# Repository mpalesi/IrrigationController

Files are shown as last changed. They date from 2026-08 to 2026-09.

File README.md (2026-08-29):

# IrrigationController Firmware

Milestone 1 is an ESP-IDF 5.5.5 foundation for the Freenove FNK0090 `DEV_KIT`.
The application core uses only logical output IDs; board selection happens in the
HAL board-composition layer.

For the DEV_KIT web test, local zones 1-8 use GPIO 16, 17, 18, 19, 21, 22, 23,
and 25 respectively. The development-only Master Valve driver uses GPIO 26.

## Host tests

```sh
cmake -S tests -B build/host-tests
cmake --build build/host-tests
ctest --test-dir build/host-tests --output-on-failure
```

## DEV_KIT build, flash, and monitor

After activating ESP-IDF 5.5.5:

```sh
idf.py -C firmware set-target esp32
idf.py -C firmware build
idf.py -C firmware -p <serial-port> flash monitor
```

`IRRIGATION_CONTROLLER` is intentionally an unconfigured safe placeholder.
It contains no GPIO, MCP23017, relay-channel, or relay-polarity assumptions.

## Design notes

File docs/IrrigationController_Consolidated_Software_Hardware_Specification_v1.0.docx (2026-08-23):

IrrigationController
Consolidated Software & Hardware Specification

Version 1.0 — Implementation Baseline

Item | Value
Purpose | Wi-Fi irrigation controller with local web interface and programmable irrigation
MCU | ESP32-WROOM-32E, LCSC C701342
PCB status | Hardware design frozen; PCB/PCBA prepared for JLCPCB
Role | Single implementation reference for firmware development and Codex

# 1. Scope and status

This document consolidates the previously separate software specifications into one implementation-oriented reference. The original documents remain archival/source material; firmware implementation should use this document as the primary baseline. The architecture remains modular, deterministic, testable, event-driven and hardware-independent above the HAL.

The PCB design has been frozen and prepared for JLCPCB assembly. Hardware-specific assumptions that still require physical-board verification are explicitly identified rather than guessed.

# 2. Final hardware platform

Block | Final hardware | Software consequence
MCU | ESP32-WROOM-32E (U301), LCSC C701342 | Main controller and Wi-Fi MCU
USB | CP2102N-Axx-xQFN24 (U302) | USB/serial development and service
I/O expander | MCP23017T-E/SS (U401) | Additional digital I/O
Output driver | ULN2803A (U501) and relay drive circuitry | Hidden behind Output Driver/HAL
Actuators | 8 × Omron G5LE-family 5 V relays K601–K608 | Eight logical output channels
Field output | J702, 8 positions; relay contacts switch 24 VAC valve circuit | Logical zones map to physical outputs
Master Valve | Remote valve controlled by Shelly 1 Gen 3 over Wi-Fi/LAN | Controlled by Master Valve Service through a dedicated Shelly client/driver; independent of local PCB relay outputs
Power | IRM-10-5 (U201), AP2112K-3.3 (U202) | 5 V / 3.3 V logic rails
Inputs | J703 INPUT1, J704 INPUT2 | Two external digital inputs
Controls | SW301 RESET, SW302 BOOT | Reset/recovery
Status | D301 status; D201/D202 power; D601–D608 relay LEDs | Diagnostics/status

Application code must not depend on raw ESP32 GPIO numbers, MCP23017 registers, ULN2803 details or relay implementation. These belong to the HAL/output-driver layer.

# 3. Hardware-aligned decisions

- The ESP32-WROOM-32E is the primary controller.
- The eight relay channels are the physical actuator resources. Higher layers use logical Output/Zone IDs.
- The eight irrigation zones are controlled locally by the PCB relay outputs. The Master Valve is a remote actuator controlled by a Shelly 1 Gen 3 over the network and is therefore not part of the PCB relay/output mapping.
- The Master Valve Service communicates with the Shelly through a dedicated Shelly client/driver abstraction. Communication failures, timeouts and unreachable-device conditions must be handled explicitly and must prevent unsafe irrigation sequencing.
- The exact MCP23017 channel mapping and exact logical-to-physical relay mapping must be verified on the first assembled PCB.
- All valve outputs must default to a safe OFF state at boot/reset/fault unless a deliberate, verified recovery policy says otherwise.
- No blocking delay() is permitted in the scheduler/control path.

# 4. Software architecture

Layer | Responsibility
Web UI | Presentation only
REST API / WebSocket | Transport; no irrigation business logic
Application services | Scheduler, Program, Zone, Master Valve, Configuration, Wi-Fi, OTA, Logger
Domain logic | Rules, validation, sequencing and state transitions
Command/Event infrastructure | Command Bus and Event Bus
State Store | Single source of truth for current runtime state
HAL / Drivers | ESP32, GPIO, MCP23017, relay/output hardware, Wi-Fi, storage and time

Core processing pipeline:

Request → Command → Validation → Handler → Service → State Store → Event → Subscribers

# 5. Core modules

Module | Responsibilities
Scheduler | Evaluate time/schedules and trigger programs; never drives outputs directly
Program Service | Programs, steps, sequencing, start/pause/resume/stop
Zone Service | Open/close zone, duration, enforce one active zone
Master Valve Service | Open/close the remote master valve through the Shelly client, manage delays and timeouts, and handle communication failures
Shelly Client | Network communication with the remote Shelly 1 Gen 3; provides an abstract interface for switching and obtaining the relevant device status
Output Driver | Translate logical outputs to actual ESP32/MCP23017/ULN2803/relay hardware
Configuration Manager | Persistent JSON; load/save/backup/restore
Wi-Fi Manager | Connect/reconnect, AP mode, NTP
REST Controller | Queries and Command transport
WebSocket | Real-time Event/state delivery
OTA Manager | Download, verify, install, rollback/recovery
Logger | DEBUG/INFO/WARNING/ERROR/CRITICAL
State Store | Current state only; no history or persistent configuration

# 6. Messaging model

- All state changes are initiated through immutable Commands.
- Events are immutable facts that have already happened; they do not execute business logic.
- Queries are read-only.
- The State Store is the single source of truth.
- Commands never directly generate GPIO, HTTP or hardware actions.
- Each Command has a Handler; handlers validate syntax, authorization and current state before invoking a Service.
- Events may have multiple subscribers such as Logger and WebSocket.
- Commands and Events are versioned.
- Commands should be idempotent where practical.

Command group | Initial catalog
Zone | OpenZoneCommand, CloseZoneCommand, EnableZoneCommand, DisableZoneCommand, ResetFaultCommand
Program | StartProgramCommand, PauseProgramCommand, ResumeProgramCommand, StopProgramCommand, EnableProgramCommand, DisableProgramCommand
System | RebootControllerCommand, StartOTACommand, SaveConfigurationCommand, RestoreConfigurationCommand
Network/User | ConnectWiFiCommand, DisconnectWiFiCommand, LoginCommand, LogoutCommand

# 7. Canonical data model

Canonical data is shared by configuration, State Store, Commands, Events, Queries, Results, REST, WebSocket and persistence. IDs are stable strings; GPIO numbers are never domain IDs. Timestamps are ISO-8601 UTC; durations are milliseconds.

Entity | Core fields
Zone | id, name, enabled, outputId, defaultDuration, description
Output | id, driver, channel, enabled
Step | id, type, target, duration, parameters
Program | id, name, enabled, scheduleId, ordered steps
Schedule | id, type, days, startTime
Master Valve | enabled, Shelly endpoint/device reference, confirmation policy, open/close delays/timeouts
User | id, role, enabled
State | system, zones, programs, masterValve, network, alarms
Zone State | zoneId, state, remainingTime
Program State | programId, state, currentStep
Network State | connected, RSSI, IP

# 8. State machines

Global states: BOOT, READY, RUNNING, MANUAL, OTA, MAINTENANCE, ERROR.

- BOOT → READY after successful initialization.
- READY → RUNNING on StartProgramCommand.
- READY → MANUAL when manual operation starts.
- RUNNING → READY when no program remains active or a program is stopped/completed.
- MANUAL → READY after manual operation exits.
- * → OTA on authorized StartOTACommand.
- OTA → READY after successful update/reboot.
- * → ERROR on a critical HardwareFaultEvent.
- ERROR → BOOT on RebootControllerCommand.

Program states: IDLE, STARTING, RUNNING, PAUSED, STOPPING, COMPLETED, ERROR.

Zone states: DISABLED, IDLE, OPENING, OPEN, CLOSING, FAULT.

Master Valve states: CLOSED, OPENING, OPEN, CLOSING, FAULT.

Wi-Fi states: DISCONNECTED, CONNECTING, CONNECTED, AP_MODE, ERROR.

OTA states: IDLE, DOWNLOADING, VERIFYING, INSTALLING, REBOOTING, ERROR.

# 9. Irrigation execution

1. Scheduler detects a valid schedule.
2. StartProgramCommand is generated/processed.
3. Program Service validates the program and starts it.
4. Master Valve Service commands the remote Shelly 1 Gen 3 to open the master valve. Irrigation zones are started only after the master-valve opening operation has succeeded according to the configured confirmation policy.
5. Zone Service opens one zone through the logical Output Driver.
6. The zone runs for its configured duration without blocking the rest of the firmware.
7. The zone closes and the next zone is started.
8. After the final zone, the Master Valve Service commands the Shelly 1 Gen 3 to close the master valve after the configured delay.
9. ProgramCompletedEvent is emitted and the system returns to READY when no other program is active.

The one-active-zone rule is mandatory. Logical zones are mapped to the eight physical relay outputs through configuration.

# 10. REST API

Base URL: /api/v1. JSON over UTF-8. Timestamps: ISO-8601 UTC.

Method | Endpoint | Purpose
GET | /api/v1/state | Entire State Store
GET | /api/v1/zones and /api/v1/zones/{id} | Zones
GET | /api/v1/programs and /api/v1/programs/{id} | Programs
GET | /api/v1/scheduler | Scheduler
GET | /api/v1/network | Network
GET | /api/v1/master-valve | Master valve
GET | /api/v1/system | System
GET | /api/v1/logs | Logs
POST | /api/v1/commands | Transport any supported Command

REST performs authentication/authorization and interface validation, but never implements irrigation business logic or accesses hardware directly.

# 11. WebSocket

WebSocket is the real-time notification channel. It subscribes to the Event Bus and sends relevant Events/state changes to clients using the canonical data model. It contains no domain logic and cannot directly manipulate outputs.

# 12. Persistence, time and security

- Persistent configuration is JSON and includes system, zones, outputs, programs, schedules, users, network and masterValve.
- Runtime State Store is separate from persistent configuration and logs.
- Passwords/secrets are never stored or logged in plaintext; password storage uses hashing.
- NTP is used when network time is available; canonical timestamps remain UTC.
- Scheduler timing uses millis(), FreeRTOS timers or equivalent non-blocking mechanisms.
- OTA images must be verified before installation.
- Roles are Administrator, Operator and Guest.

# 13. FreeRTOS/task model

Execution context | Role
Command Task | Receive/dispatch Commands
Scheduler Task | Evaluate schedules/time triggers
IO Task | Hardware-facing logical I/O work
Network Task | Wi-Fi/network processing
Logger Task | Asynchronous logging
OTA Task | Firmware update workflow
Web/API context | HTTP/WebSocket transport without blocking domain operations

Queues, event groups and timers are preferred for coordination. Long blocking operations must not stall irrigation control.

# 14. Error handling

Result | Meaning
OK / Success | Operation completed
Rejected | Command valid but not executable
Forbidden | Authorization failure
InvalidState | Current state does not permit operation
NotFound | Referenced entity does not exist
Timeout | Operation exceeded its limit
InternalError | Unexpected internal error

REST mapping follows the existing specification: 200/201 success, 400 malformed request, 401 unauthenticated, 403 unauthorized, 404 not found, 409 incompatible state, 422 valid but not executable, 500 internal error.

# 15. Logging and testing

- Log important program, master-valve, zone, network, configuration, OTA and fault events.
- Levels: DEBUG, INFO, WARNING, ERROR, CRITICAL.
- Domain modules must be unit-testable without an ESP32.
- State-machine transitions require normal, invalid, timeout and fault tests.
- REST/WebSocket tests are independent of domain logic.
- After the first assembled PCB arrives, perform hardware-in-the-loop tests before declaring the hardware support complete.

# 16. First-board hardware verification checklist

- Verify exact MCP23017 channel assignment.
- Verify exact logical-to-physical relay mapping K601–K608.
- Verify relay active polarity and ULN2803A drive behavior.
- Verify all eight 24 VAC outputs under the intended field load.
- Verify INPUT1 and INPUT2 electrical behavior.
- Verify RESET/BOOT behavior.
- Verify power-up/reset/watchdog behavior leaves valve outputs safely OFF.
- Verify Wi-Fi loss does not create unsafe actuator behavior.
- Verify OTA/reboot behavior leaves outputs in a safe state.

# 17. Recommended firmware repository structure

firmware/
app/
services/ state/ commands/ events/ scheduler/
domain/
zones/ programs/ master_valve/
infrastructure/
persistence/ logging/ network/ ota/
hal/
esp32/ gpio/ mcp23017/ outputs/
interfaces/
rest/ websocket/
main/
tests/
docs/
AGENTS.md

# 18. Implementation order

10. Create repository skeleton, build system and AGENTS.md.
11. Implement HAL and verify the finalized PCB output/input mapping.
12. Implement State Store and canonical structures.
13. Implement Command/Event infrastructure and Result types.
14. Implement Zone Service and Output Driver.
15. Implement Master Valve Service.
16. Implement Program Service and program state machine.
17. Implement Scheduler and time synchronization.
18. Implement persistent configuration.
19. Implement Wi-Fi Manager.
20. Implement REST API and authentication.
21. Implement WebSocket event delivery.
22. Implement OTA.
23. Add unit, integration and hardware-in-the-loop tests.

# 19. Important reconciliation with the original drafts

The consolidated baseline retains the Command Bus + Event Bus + State Store architecture and its modular/HAL principles. The finalized hardware architecture distinguishes between the eight local irrigation-zone outputs provided by the PCB and the remote Master Valve. The eight irrigation zones are controlled through the PCB Output Driver, while the Master Valve is a remote actuator controlled through a Shelly 1 Gen 3 over the network. Master Valve communication is isolated behind a dedicated Shelly client/driver interface. Exact MCP23017 and relay mappings that cannot be established from the design documentation remain first-board verification items rather than assumptions..

# 20. Source documents

- Functional Specifications / requirements
- 01 - Software Architecture Document (SAD) v1.0
- 02 - Domain Model v1.0
- 03 - Data Dictionary v1.0
- 04 - Protocol Design Document (PDD) v1.0
- 05 - Canonical Data Model (CDM) v1.0
- 06 - State Machine Specification v1.0
- 07 - System State Machine v1.0
- 08 - Task Model v1.0
- 09 - REST API Specification v1.0
- 10 - WebSocket Protocol Specification v1.0

This document is the implementation baseline; the source documents remain useful for detailed traceability and historical context.

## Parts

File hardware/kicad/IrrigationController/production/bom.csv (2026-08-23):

Designator | Footprint | Quantity | Value | LCSC Part #
C201 | C165631_CAP-SMD_BD6_3-L6_6-W6_6-FD | 1 | 100uF | C165631
C202 | C14663_C0603 | 1 | 100nF | C14663
C203, C204, C303 | C15849_C0603 | 3 | 1uF | C15849
C301, C306, C401, C703, C704 | C14663_C0603 | 5 | 100 nF | C14663
C302, C402 | C13585_C1206 | 2 | 10 uF | C13585
C305 | C19666_C0603 | 1 | 4.7 uF | C19666
D601, D602, D603, D604, D605, D606, D607, D608 | C12065_LED0603-RD | 8 | GREEN | C12065
F101 | C3131_FUSE-TH_L22_6-W9_0 | 1 | T2A | C3131
J101 | C2915640_CONN-TH_3P-P5_08_DIBO_DB128V-5_08-3P-X | 1 | AC IN | C2915640
J102 | C2915641_CONN-TH_4P-P5_08_DIBO_DB128V-5_08 | 1 | 4P 5.08mm (SWITCH) | C2915641
J201 | C5360898_HDR-TH_2P-P2_54-V-M-3 | 1 | PWR_5V | C5360898
J202 | C5360898_HDR-TH_2P-P2_54-V-M-3 | 1 | PWR_3V3 | C5360898
J301 | C5184243_USB-C-SMD_MC-311D | 1 | USB4105-GF-A-120 | C5184243
J302 | C5360898_HDR-TH_2P-P2_54-V-M-3 | 1 | STATUS | C5360898
J701 | C2915639_CONN-TH_2P-P5_08_DIBO_DB128V-5_08 | 1 | 24VAC IN | C2915639
J702 | C90065_CONN-TH_8P-P5_08_1757307 | 1 | VALVES | C90065
J703 | C2915639_CONN-TH_2P-P5_08_DIBO_DB128V-5_08 | 1 | INPUT1 | C2915639
J704 | C2915639_CONN-TH_2P-P5_08_DIBO_DB128V-5_08 | 1 | INPUT2 | C2915639
K601, K602, K603, K604, K605, K606, K607, K608 | C116963_RELAY-TH_G5LE-14-XX | 8 | G5LE-1 | C116963
Q301, Q302 | C2150_SOT-23-3_L2_9-W1_3-P1_90-LS2_4-BR | 2 | SS8050 | C2150
R201, R202, R307, R308, R601, R602, R603, R604, R605, R606, R607, R608 | C22548_R0603 | 12 | 1K | C22548
R301, R302, R303, R304, R401, R703, R704 | C25804_R0603 | 7 | 10k | C25804
R305, R306 | C23186_R0603 | 2 | 5.1k | C23186
R405, R406 | C23162_R0603 | 2 | 4.7k | C23162
RV101 | C233160_RES-TH_L17_0-W10_0-P7_50-D0_8-S10_00 | 1 | S14K275 | C233160
SW301 | C2845315_SW-SMD_4P-L6_0-W6_0-P4_50-LS10_0_TL3301EF160QG | 1 | RESET | C2845315
SW302 | C2845315_SW-SMD_4P-L6_0-W6_0-P4_50-LS10_0_TL3301EF160QG | 1 | BOOT | C2845315
U201 | C2857903_PWRM-TH_4P-L45_7-W25_4-P8_0 | 1 | IRM-10-5 | C2857903
U202 | C51118_SOT-25-5_L2_9-W1_6-P0_95-LS2_8-BL | 1 | AP2112K-3.3 | C51118
U301 | C701342_WIFI-SMD_ESP32-WROOM-32E | 1 | ESP32-WROOM-32E | C701342
U302 | C969151_QFN-24_L4_0-W4_0-P0_50-TL-EP2_6 | 1 | CP2102N-A02-GQFN24R | C969151
U303 | C94934_SOT-9X3-3_L1_0-W0_8-P0_35-LS1_0-BR | 1 | TPD2EUSB30A | C94934
U401 | C558584_SSOP-28_L10_2-W5_3-P0_65-LS7_8-BL | 1 | MCP23017T-E/SS | C558584
U501 | C181731_SOIC-18_L11_6-W7_5-P1_27-LS10_3-BL | 1 | ULN2803A | C181731

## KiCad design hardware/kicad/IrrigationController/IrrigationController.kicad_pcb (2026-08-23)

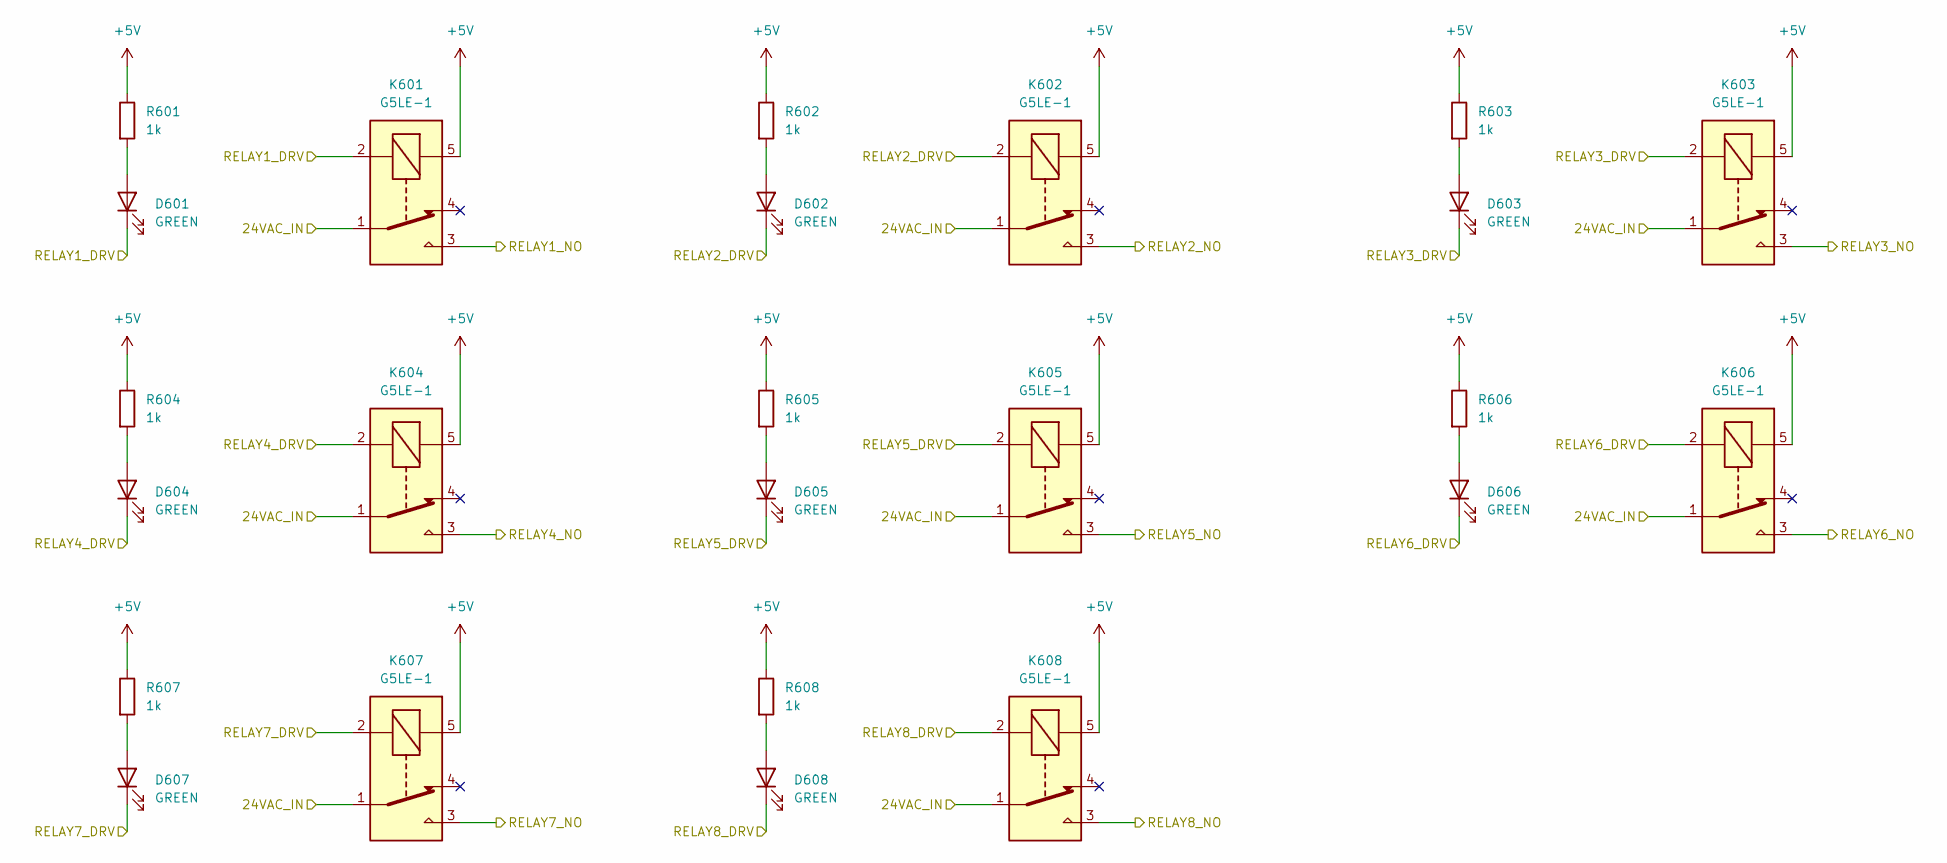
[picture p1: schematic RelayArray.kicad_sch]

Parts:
D601, D602, D603, D604, D605, D606, D607, D608: GREEN; C12065_LED0603-RD; LCSC Part # C12065
K601, K602, K603, K604, K605, K606, K607, K608: G5LE-1; C116963_RELAY-TH_G5LE-14-XX; LCSC Part # C116963
R601, R602, R603, R604, R605, R606, R607, R608: 1k; C22548_R0603; LCSC Part # C22548

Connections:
+5V: K601.5, K602.5, K603.5, K604.5, K605.5, K606.5, K607.5, K608.5, R601.1, R602.1, R603.1, R604.1, R605.1, R606.1, R607.1, R608.1; also elsewhere on the board
/Drivers/RELAY1_DRV: D601.1 (K), K601.2; also elsewhere on the board
/Drivers/RELAY2_DRV: D602.1 (K), K602.2; also elsewhere on the board
/Drivers/RELAY3_DRV: D603.1 (K), K603.2; also elsewhere on the board
/Drivers/RELAY4_DRV: D604.1 (K), K604.2; also elsewhere on the board
/Drivers/RELAY5_DRV: D605.1 (K), K605.2; also elsewhere on the board
/Drivers/RELAY6_DRV: D606.1 (K), K606.2; also elsewhere on the board
/Drivers/RELAY7_DRV: D607.1 (K), K607.2; also elsewhere on the board
/Drivers/RELAY8_DRV: D608.1 (K), K608.2; also elsewhere on the board
/RelayArray/24VAC_IN: K601.1, K602.1, K603.1, K604.1, K605.1, K606.1, K607.1, K608.1; also elsewhere on the board
/RelayArray/RELAY1_NO: K601.3; also elsewhere on the board
/RelayArray/RELAY2_NO: K602.3; also elsewhere on the board
/RelayArray/RELAY3_NO: K603.3; also elsewhere on the board
/RelayArray/RELAY4_NO: K604.3; also elsewhere on the board
/RelayArray/RELAY5_NO: K605.3; also elsewhere on the board
/RelayArray/RELAY6_NO: K606.3; also elsewhere on the board
/RelayArray/RELAY7_NO: K607.3; also elsewhere on the board
/RelayArray/RELAY8_NO: K608.3; also elsewhere on the board
unnamed: D601.2 (A), R601.2
unnamed: D602.2 (A), R602.2
unnamed: D603.2 (A), R603.2
unnamed: D604.2 (A), R604.2
unnamed: D605.2 (A), R605.2
unnamed: D606.2 (A), R606.2
unnamed: D607.2 (A), R607.2
unnamed: D608.2 (A), R608.2

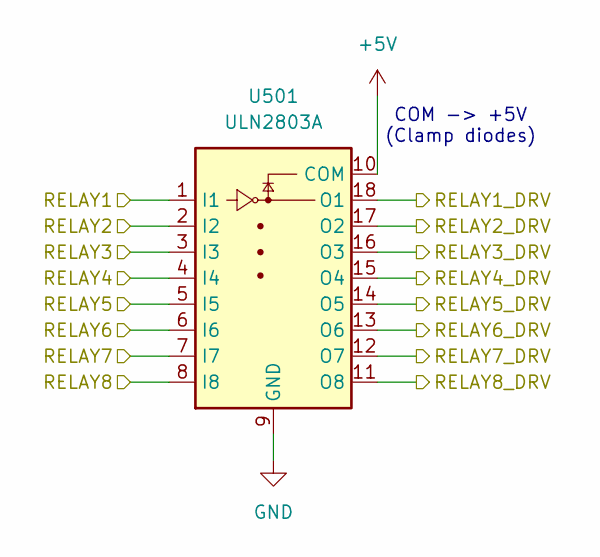
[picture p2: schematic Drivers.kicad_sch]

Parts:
U501: ULN2803A; C181731_SOIC-18_L11_6-W7_5-P1_27-LS10_3-BL; LCSC Part # C181731

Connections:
+5V: U501.10 (COM); also elsewhere on the board
/Drivers/RELAY1: U501.1 (I1); also elsewhere on the board
/Drivers/RELAY1_DRV: U501.18 (O1); also elsewhere on the board
/Drivers/RELAY2: U501.2 (I2); also elsewhere on the board
/Drivers/RELAY2_DRV: U501.17 (O2); also elsewhere on the board
/Drivers/RELAY3: U501.3 (I3); also elsewhere on the board
/Drivers/RELAY3_DRV: U501.16 (O3); also elsewhere on the board
/Drivers/RELAY4: U501.4 (I4); also elsewhere on the board
/Drivers/RELAY4_DRV: U501.15 (O4); also elsewhere on the board
/Drivers/RELAY5: U501.5 (I5); also elsewhere on the board
/Drivers/RELAY5_DRV: U501.14 (O5); also elsewhere on the board
/Drivers/RELAY6: U501.6 (I6); also elsewhere on the board
/Drivers/RELAY6_DRV: U501.13 (O6); also elsewhere on the board
/Drivers/RELAY7: U501.7 (I7); also elsewhere on the board
/Drivers/RELAY7_DRV: U501.12 (O7); also elsewhere on the board
/Drivers/RELAY8: U501.8 (I8); also elsewhere on the board
/Drivers/RELAY8_DRV: U501.11 (O8); also elsewhere on the board
GND: U501.9 (GND); also elsewhere on the board

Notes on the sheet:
COM -> +5V (Clamp diodes)

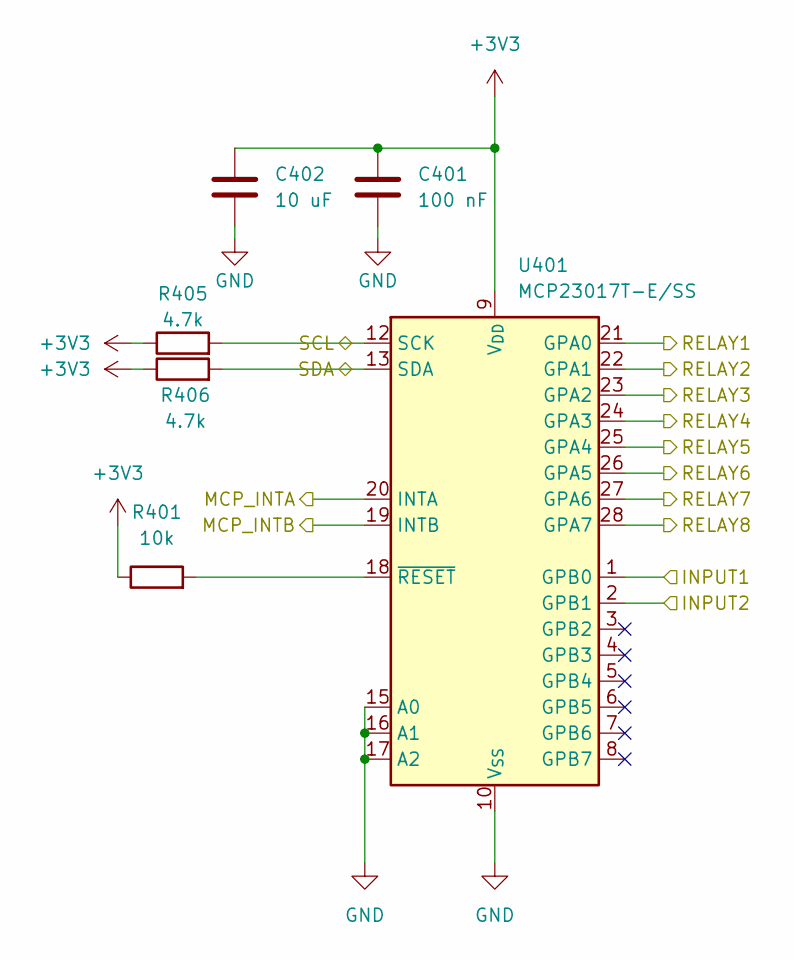
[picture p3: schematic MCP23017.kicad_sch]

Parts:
C401: 100 nF; C14663_C0603; LCSC Part # C14663
C402: 10 uF; C13585_C1206; LCSC Part # C13585
R401: 10k; C25804_R0603; LCSC Part # C25804
R405, R406: 4.7k; C23162_R0603; LCSC Part # C23162
U401: MCP23017T-E/SS; C558584_SSOP-28_L10_2-W5_3-P0_65-LS7_8-BL; LCSC Part # C558584

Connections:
+3V3: C401.1, C402.1, R401.1, R405.1, R406.1, U401.9 (V_{DD}); also elsewhere on the board
/Drivers/RELAY1: U401.21 (GPA0); also elsewhere on the board
/Drivers/RELAY2: U401.22 (GPA1); also elsewhere on the board
/Drivers/RELAY3: U401.23 (GPA2); also elsewhere on the board
/Drivers/RELAY4: U401.24 (GPA3); also elsewhere on the board
/Drivers/RELAY5: U401.25 (GPA4); also elsewhere on the board
/Drivers/RELAY6: U401.26 (GPA5); also elsewhere on the board
/Drivers/RELAY7: U401.27 (GPA6); also elsewhere on the board
/Drivers/RELAY8: U401.28 (GPA7); also elsewhere on the board
/ESP32/MCP_INTA: U401.20 (INTA); also elsewhere on the board
/ESP32/MCP_INTB: U401.19 (INTB); also elsewhere on the board
/ESP32/SCL: R405.2, U401.12 (SCK); also elsewhere on the board
/ESP32/SDA: R406.2, U401.13 (SDA); also elsewhere on the board
/MCP23017/INPUT1: U401.1 (GPB0); also elsewhere on the board
/MCP23017/INPUT2: U401.2 (GPB1); also elsewhere on the board
GND: C401.2, C402.2, U401.10 (V_{SS}), U401.15 (A0), U401.16 (A1), U401.17 (A2); also elsewhere on the board
unnamed: R401.2, U401.18 (~RESET)

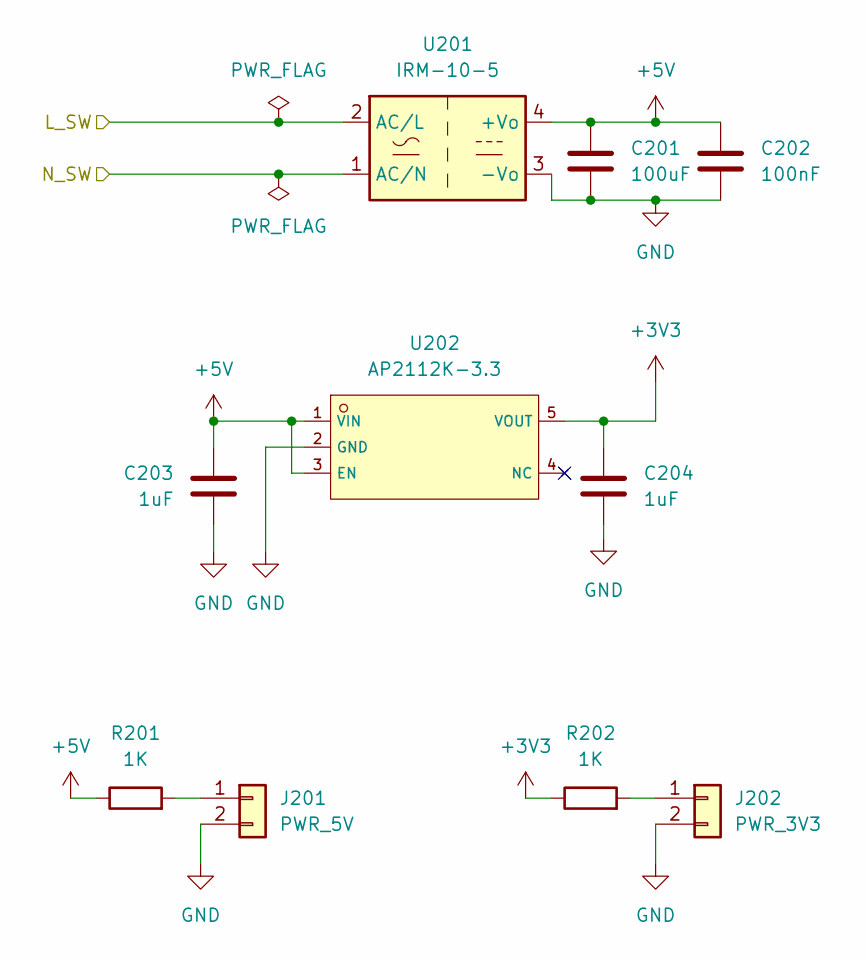
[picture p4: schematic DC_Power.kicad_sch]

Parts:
C201: 100uF; C165631_CAP-SMD_BD6_3-L6_6-W6_6-FD; LCSC Part # C165631
C202: 100nF; C14663_C0603; LCSC Part # C14663
C203, C204: 1uF; C15849_C0603; LCSC Part # C15849
J201: PWR_5V; C5360898_HDR-TH_2P-P2_54-V-M-3; LCSC Part # C5360898
J202: PWR_3V3; C5360898_HDR-TH_2P-P2_54-V-M-3; LCSC Part # C5360898
R201, R202: 1K; C22548_R0603; LCSC Part # C22548
U201: IRM-10-5; C2857903_PWRM-TH_4P-L45_7-W25_4-P8_0; LCSC Part # C2857903
U202: AP2112K-3.3; C51118_SOT-25-5_L2_9-W1_6-P0_95-LS2_8-BL; LCSC Part # C51118

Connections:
+3V3: C204.1, R202.1, U202.5 (VOUT); also elsewhere on the board
+5V: C201.1, C202.1, C203.1, R201.1, U201.4 (+Vo), U202.1 (VIN), U202.3 (EN); also elsewhere on the board
/AC_Input/L_SW: U201.2 (AC/L); also elsewhere on the board
/AC_Input/N_SW: U201.1 (AC/N); also elsewhere on the board
GND: C201.2, C202.2, C203.2, C204.2, J201.2, J202.2, U201.3 (-Vo), U202.2 (GND); also elsewhere on the board
unnamed: J201.1, R201.2
unnamed: J202.1, R202.2

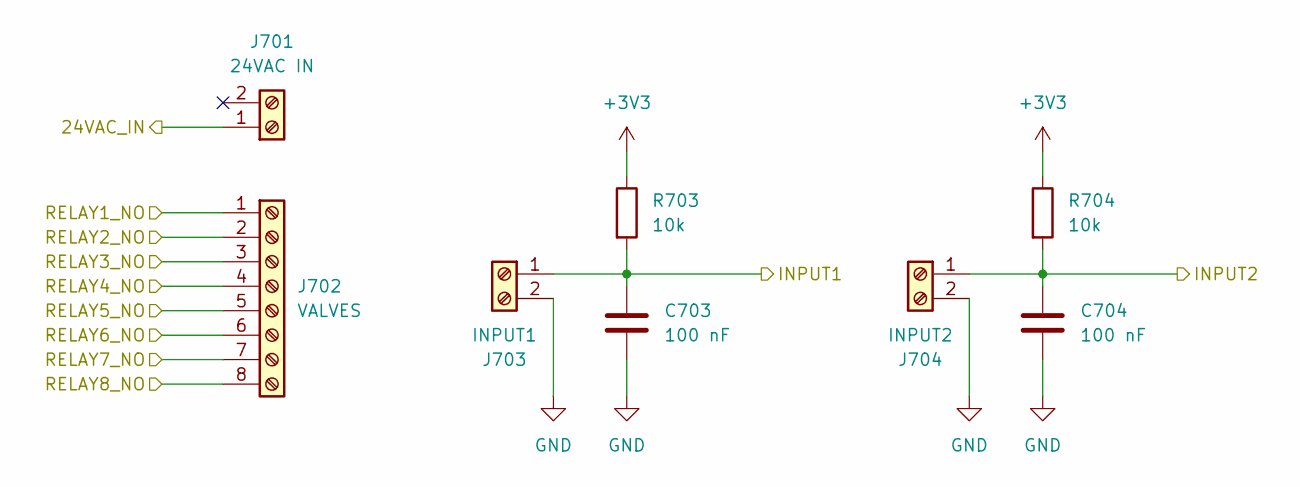
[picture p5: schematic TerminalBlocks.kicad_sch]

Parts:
C703, C704: 100 nF; C14663_C0603; LCSC Part # C14663
J701: 24VAC IN; C2915639_CONN-TH_2P-P5_08_DIBO_DB128V-5_08; LCSC Part # C2915639
J702: VALVES; C90065_CONN-TH_8P-P5_08_1757307; LCSC Part # C90065
J703: INPUT1; C2915639_CONN-TH_2P-P5_08_DIBO_DB128V-5_08; LCSC Part # C2915639
J704: INPUT2; C2915639_CONN-TH_2P-P5_08_DIBO_DB128V-5_08; LCSC Part # C2915639
R703, R704: 10k; C25804_R0603; LCSC Part # C25804

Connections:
+3V3: R703.1, R704.1; also elsewhere on the board
/MCP23017/INPUT1: C703.1, J703.1, R703.2; also elsewhere on the board
/MCP23017/INPUT2: C704.1, J704.1, R704.2; also elsewhere on the board
/RelayArray/24VAC_IN: J701.1 (Pin_1_1); also elsewhere on the board
/RelayArray/RELAY1_NO: J702.1; also elsewhere on the board
/RelayArray/RELAY2_NO: J702.2; also elsewhere on the board
/RelayArray/RELAY3_NO: J702.3; also elsewhere on the board
/RelayArray/RELAY4_NO: J702.4; also elsewhere on the board
/RelayArray/RELAY5_NO: J702.5; also elsewhere on the board
/RelayArray/RELAY6_NO: J702.6; also elsewhere on the board
/RelayArray/RELAY7_NO: J702.7; also elsewhere on the board
/RelayArray/RELAY8_NO: J702.8; also elsewhere on the board
GND: C703.2, C704.2, J703.2, J704.2; also elsewhere on the board

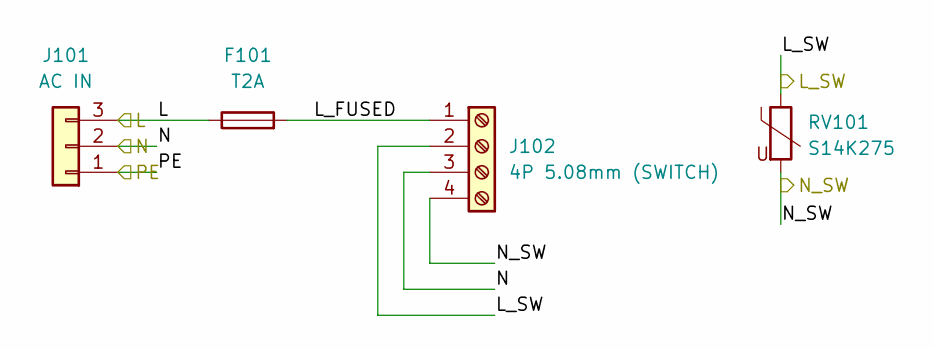
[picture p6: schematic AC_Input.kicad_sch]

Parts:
F101: T2A; C3131_FUSE-TH_L22_6-W9_0; LCSC Part # C3131
J101: AC IN; C2915640_CONN-TH_3P-P5_08_DIBO_DB128V-5_08-3P-X; LCSC Part # C2915640
J102: 4P 5.08mm (SWITCH); C2915641_CONN-TH_4P-P5_08_DIBO_DB128V-5_08; LCSC Part # C2915641
RV101: S14K275; C233160_RES-TH_L17_0-W10_0-P7_50-D0_8-S10_00; LCSC Part # C233160

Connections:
/AC_Input/L: F101.1, J101.3
/AC_Input/L_FUSED: F101.2, J102.1
/AC_Input/L_SW: J102.2, RV101.1; also elsewhere on the board
/AC_Input/N: J101.2, J102.3
/AC_Input/N_SW: J102.4, RV101.2; also elsewhere on the board
/AC_Input/PE: J101.1

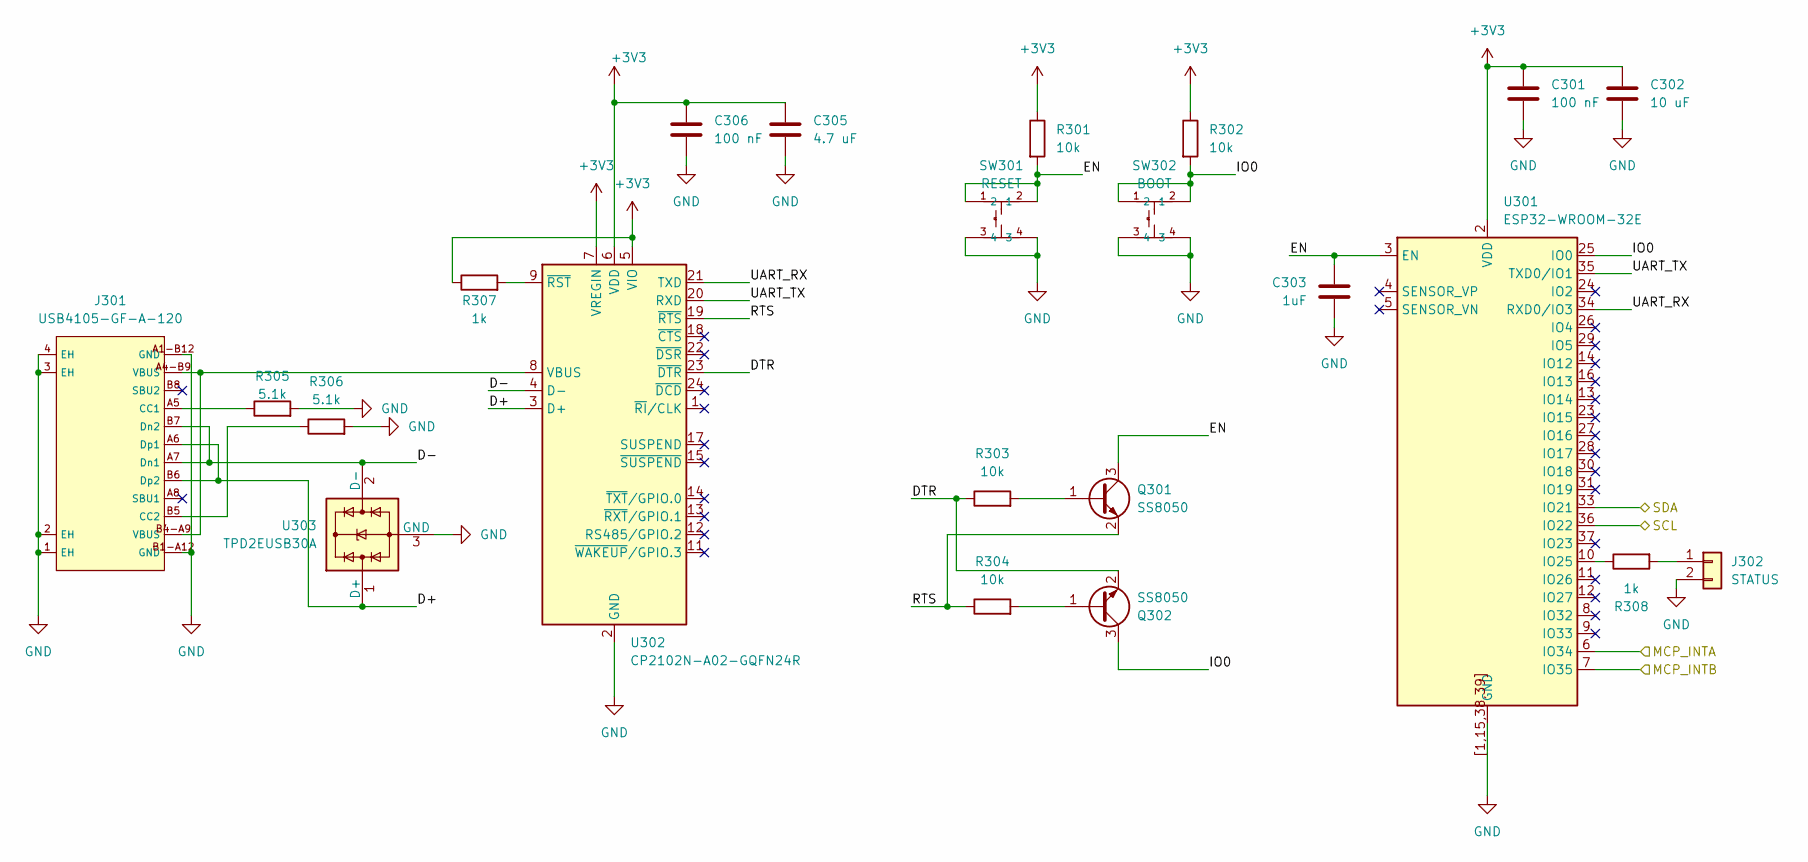
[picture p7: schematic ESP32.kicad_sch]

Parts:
C301, C306: 100 nF; C14663_C0603; LCSC Part # C14663
C302: 10 uF; C13585_C1206; LCSC Part # C13585
C303: 1uF; C15849_C0603; LCSC Part # C15849
C305: 4.7 uF; C19666_C0603; LCSC Part # C19666
J301: USB4105-GF-A-120; C5184243_USB-C-SMD_MC-311D; LCSC C5184243
J302: STATUS; C5360898_HDR-TH_2P-P2_54-V-M-3; LCSC Part # C5360898
Q301, Q302: SS8050; C2150_SOT-23-3_L2_9-W1_3-P1_90-LS2_4-BR; LCSC Part # C2150
R301, R302, R303, R304: 10k; C25804_R0603; LCSC Part # C25804
R305, R306: 5.1k; C23186_R0603; LCSC Part # C23186
R307, R308: 1k; C22548_R0603; LCSC Part # C22548
SW301: RESET; C2845315_SW-SMD_4P-L6_0-W6_0-P4_50-LS10_0_TL3301EF160QG; LCSC Part # C2845315
SW302: BOOT; C2845315_SW-SMD_4P-L6_0-W6_0-P4_50-LS10_0_TL3301EF160QG; LCSC Part # C2845315
U301: ESP32-WROOM-32E; C701342_WIFI-SMD_ESP32-WROOM-32E; LCSC Part # C701342
U302: CP2102N-A02-GQFN24R; C969151_QFN-24_L4_0-W4_0-P0_50-TL-EP2_6; LCSC Part # C969151
U303: TPD2EUSB30A; C94934_SOT-9X3-3_L1_0-W0_8-P0_35-LS1_0-BR; LCSC Part # C94934

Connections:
+3V3: C301.1, C302.1, C305.1, C306.1, R301.1, R302.1, R307.1, U301.2 (VDD), U302.5 (VIO), U302.6 (VDD), U302.7 (VREGIN); also elsewhere on the board
/ESP32/D+: J301.A6 (Dp1), J301.B6 (Dp2), U302.3 (D+), U303.1 (D+)
/ESP32/D-: J301.A7 (Dn1), J301.B7 (Dn2), U302.4 (D-), U303.2 (D-)
/ESP32/DTR: Q302.2 (E), R303.1, U302.23 (~DTR)
/ESP32/EN: C303.1, Q301.3 (C), R301.2, SW301.1, SW301.2, U301.3 (EN)
/ESP32/IO0: Q302.3 (C), R302.2, SW302.1, SW302.2, U301.25 (IO0)
/ESP32/MCP_INTA: U301.6 (IO34); also elsewhere on the board
/ESP32/MCP_INTB: U301.7 (IO35); also elsewhere on the board
/ESP32/RTS: Q301.2 (E), R304.1, U302.19 (~RTS)
/ESP32/SCL: U301.36 (IO22); also elsewhere on the board
/ESP32/SDA: U301.33 (IO21); also elsewhere on the board
/ESP32/UART_RX: U301.34 (RXD0/IO3), U302.21 (TXD)
/ESP32/UART_TX: U301.35 (TXD0/IO1), U302.20 (RXD)
GND: C301.2, C302.2, C303.2, C305.2, C306.2, J301.1 (EH), J301.2 (EH), J301.3 (EH), J301.4 (EH), J301.A1-B12 (GND), J301.B1-A12 (GND), J302.2, R305.2, R306.2, SW301.3, SW301.4, SW302.3, SW302.4, U301.1 (GND), U301.15 (GND), U301.38 (GND), U301.39 (GND), U301.[1,15,38,39] (GND), U302.2 (GND), U302.25 (GND), U303.3 (GND); also elsewhere on the board
unnamed: J301.A5 (CC1), R305.1
unnamed: J301.B5 (CC2), R306.1
unnamed: J302.1, R308.2
unnamed: Q301.1 (B), R303.2
unnamed: Q302.1 (B), R304.2
unnamed: R308.1, U301.10 (IO25)
unnamed: J301.A4-B9 (VBUS), J301.B4-A9 (VBUS), U302.8 (VBUS)
unnamed: R307.2, U302.9 (~RST)

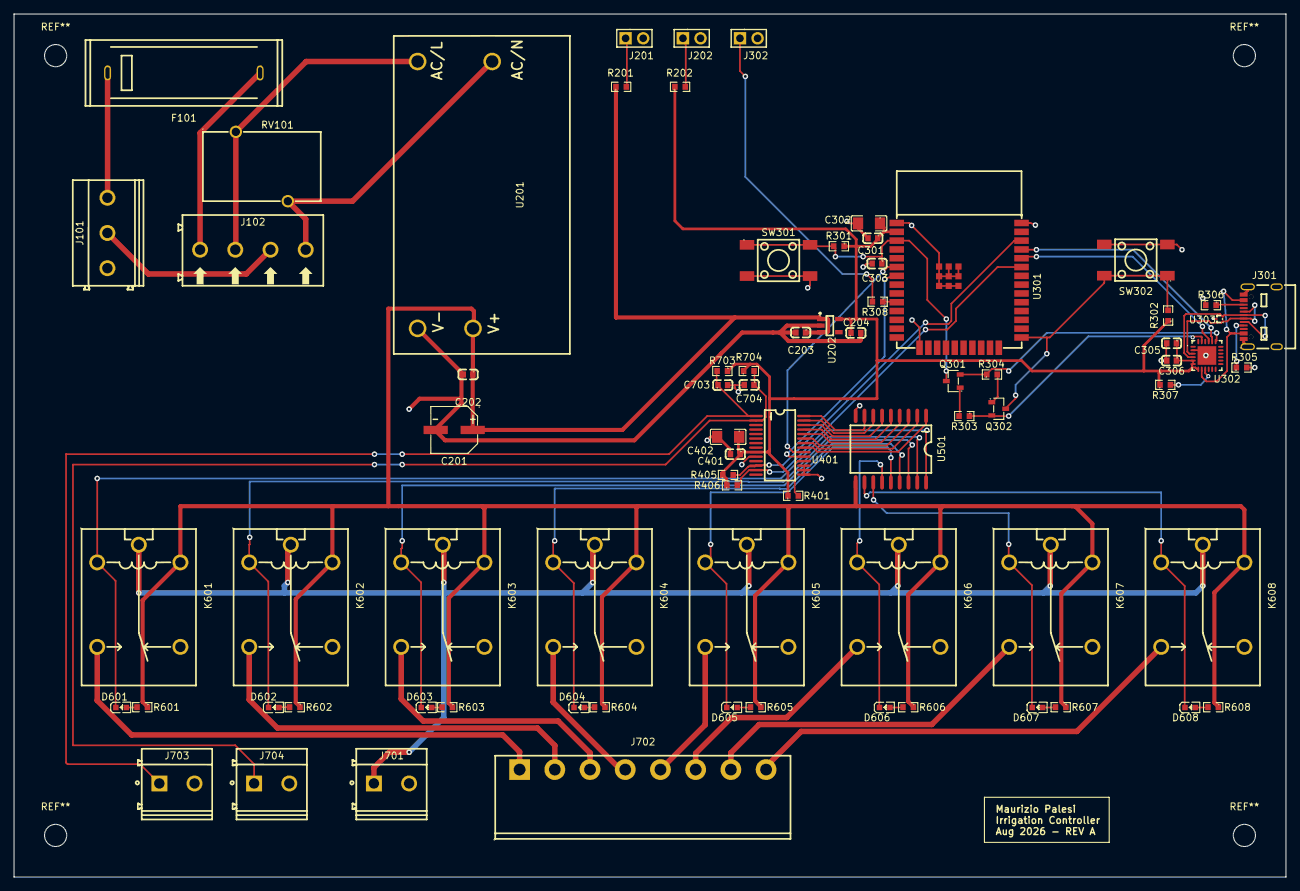
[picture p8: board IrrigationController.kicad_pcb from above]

Board: 2 copper layers, 183.5 x 124.5 mm, 75 parts (0 on the bottom side), 66 nets.

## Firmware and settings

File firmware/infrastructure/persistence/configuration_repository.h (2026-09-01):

#pragma once

#include <stddef.h>
#include <stdint.h>

#include "app/configuration/irrigation_configuration.h"

#define CONFIGURATION_REPOSITORY_SLOT_A "cfg_a"
#define CONFIGURATION_REPOSITORY_SLOT_B "cfg_b"
#define CONFIGURATION_REPOSITORY_MAGIC 0x47464349U
#define CONFIGURATION_REPOSITORY_HEADER_SIZE 16U
#define CONFIGURATION_REPOSITORY_MAX_TEXT_SIZE IRRIGATION_CONFIGURATION_ID_SIZE
#define CONFIGURATION_REPOSITORY_MAX_PAYLOAD_SIZE \
    (13U + IRRIGATION_MAX_ZONES * (2U * CONFIGURATION_REPOSITORY_MAX_TEXT_SIZE) + \
     IRRIGATION_MAX_PROGRAMS * (2U * CONFIGURATION_REPOSITORY_MAX_TEXT_SIZE + 1U + \
                                IRRIGATION_MAX_PROGRAM_STEPS * (CONFIGURATION_REPOSITORY_MAX_TEXT_SIZE + 4U)) + \
     IRRIGATION_MAX_SCHEDULES * (2U * CONFIGURATION_REPOSITORY_MAX_TEXT_SIZE + 4U))
#define CONFIGURATION_REPOSITORY_MAX_BLOB_SIZE \
    (CONFIGURATION_REPOSITORY_HEADER_SIZE + CONFIGURATION_REPOSITORY_MAX_PAYLOAD_SIZE)

typedef enum {
    CONFIGURATION_REPOSITORY_OK = 0,
    CONFIGURATION_REPOSITORY_NOT_FOUND,
    CONFIGURATION_REPOSITORY_CORRUPT,
    CONFIGURATION_REPOSITORY_INCOMPATIBLE,
    CONFIGURATION_REPOSITORY_INVALID_CONFIGURATION,
    CONFIGURATION_REPOSITORY_STORAGE_ERROR,
} ConfigurationRepositoryResult;

typedef ConfigurationRepositoryResult (*ConfigurationRepositoryRead)(void *context, const char *key,
                                                                      uint8_t *buffer, size_t capacity,
                                                                      size_t *length);
typedef ConfigurationRepositoryResult (*ConfigurationRepositoryWrite)(void *context, const char *key,
                                                                       const uint8_t *buffer, size_t length);
typedef ConfigurationRepositoryResult (*ConfigurationRepositoryCommit)(void *context);

typedef struct {
    void *context;
    ConfigurationRepositoryRead read;
    ConfigurationRepositoryWrite write;
    ConfigurationRepositoryCommit commit;
} ConfigurationRepositoryStorage;

typedef struct {
    ConfigurationRepositoryStorage storage;
    uint8_t slot_buffers[2][CONFIGURATION_REPOSITORY_MAX_BLOB_SIZE];
    IrrigationConfiguration slot_configurations[2];
} ConfigurationRepository;

void configuration_repository_init(ConfigurationRepository *repository,
                                   ConfigurationRepositoryStorage storage);
ConfigurationRepositoryResult configuration_repository_encode(
    const IrrigationConfiguration *configuration, uint32_t generation, uint8_t *blob, size_t capacity,
    size_t *blob_length);
ConfigurationRepositoryResult configuration_repository_decode(
    const uint8_t *blob, size_t blob_length, IrrigationConfiguration *configuration, uint32_t *generation,
    const Zone *board_zones, size_t board_zone_count);
ConfigurationRepositoryResult configuration_repository_load(ConfigurationRepository *repository,
                                                             IrrigationConfiguration *configuration,
                                                             uint32_t *generation, const Zone *board_zones,
                                                             size_t board_zone_count);
ConfigurationRepositoryResult configuration_repository_save(ConfigurationRepository *repository,
                                                             const IrrigationConfiguration *configuration,
                                                             const Zone *board_zones, size_t board_zone_count);

ConfigurationRepositoryResult nvs_configuration_repository_init(ConfigurationRepository *repository);
void nvs_configuration_repository_deinit(void);

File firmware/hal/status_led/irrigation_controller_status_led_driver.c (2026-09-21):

#include "hal/status_led/irrigation_controller_status_led_driver.h"

#include "driver/gpio.h"
#include "esp_log.h"

#define IRRIGATION_CONTROLLER_STATUS_LED_GPIO GPIO_NUM_25
#define STATUS_LED_SLOW_HALF_PERIOD_US 500000U
#define STATUS_LED_FAST_HALF_PERIOD_US 125000U

static const char *TAG = "production_status_led";

static void set_led_level(bool on)
{
    (void)gpio_set_level(IRRIGATION_CONTROLLER_STATUS_LED_GPIO, on ? 1 : 0);
}

static uint64_t blink_half_period_us(StatusLedState state)
{
    return state == STATUS_LED_STATE_FAULT ? STATUS_LED_FAST_HALF_PERIOD_US
                                           : STATUS_LED_SLOW_HALF_PERIOD_US;
}

static void blink_timer_callback(void *context)
{
    IrrigationControllerStatusLedDriver *driver = context;
    portENTER_CRITICAL(&driver->lock);
    driver->led_on = driver->state == STATUS_LED_STATE_READY || !driver->led_on;
    /* Keep the GPIO write serialized with state transitions, including READY. */
    set_led_level(driver->led_on);
    portEXIT_CRITICAL(&driver->lock);
}

static IrrigationResult set_state(StatusLedDriver *base, StatusLedState state)
{
    IrrigationControllerStatusLedDriver *driver = (IrrigationControllerStatusLedDriver *)base;
    if (driver == NULL || !driver->initialized) return IRRIGATION_RESULT_INVALID_STATE;

    portENTER_CRITICAL(&driver->lock);
    const bool unchanged = driver->state == state;
    portEXIT_CRITICAL(&driver->lock);
    if (unchanged) return IRRIGATION_RESULT_OK;

    (void)esp_timer_stop(driver->timer);
    portENTER_CRITICAL(&driver->lock);
    driver->state = state;
    /* READY stays ON; blinking states start with their ON half-period. */
    driver->led_on = true;
    set_led_level(driver->led_on);
    portEXIT_CRITICAL(&driver->lock);

    if (state != STATUS_LED_STATE_READY &&
        esp_timer_start_periodic(driver->timer, blink_half_period_us(state)) != ESP_OK) {
        portENTER_CRITICAL(&driver->lock);
        driver->led_on = driver->state == STATUS_LED_STATE_READY;
        set_led_level(driver->led_on);
        portEXIT_CRITICAL(&driver->lock);
        return IRRIGATION_RESULT_INTERNAL_ERROR;
    }
    return IRRIGATION_RESULT_OK;
}

static const StatusLedDriverVTable IRRIGATION_CONTROLLER_STATUS_LED_DRIVER_VTABLE = {
    .set_state = set_state,
};

IrrigationResult irrigation_controller_status_led_driver_init(IrrigationControllerStatusLedDriver *driver)
{
    if (driver == NULL) return IRRIGATION_RESULT_REJECTED;
    *driver = (IrrigationControllerStatusLedDriver){
        .base.vtable = &IRRIGATION_CONTROLLER_STATUS_LED_DRIVER_VTABLE,
        .lock = portMUX_INITIALIZER_UNLOCKED,
        .state = STATUS_LED_STATE_READY,
    };
    if (gpio_reset_pin(IRRIGATION_CONTROLLER_STATUS_LED_GPIO) != ESP_OK ||
        gpio_set_level(IRRIGATION_CONTROLLER_STATUS_LED_GPIO, 0) != ESP_OK ||
        gpio_set_direction(IRRIGATION_CONTROLLER_STATUS_LED_GPIO, GPIO_MODE_OUTPUT) != ESP_OK) {
        ESP_LOGE(TAG, "GPIO25 safe initialization failed");
        return IRRIGATION_RESULT_INTERNAL_ERROR;
    }
    const esp_timer_create_args_t timer_arguments = {
        .callback = blink_timer_callback,
        .arg = driver,
        .name = "status_led",
    };
    if (esp_timer_create(&timer_arguments, &driver->timer) != ESP_OK) {
        ESP_LOGE(TAG, "blink timer creation failed");
        return IRRIGATION_RESULT_INTERNAL_ERROR;
    }
    driver->initialized = true;
    return set_state(&driver->base, STATUS_LED_STATE_BOOTING);
}

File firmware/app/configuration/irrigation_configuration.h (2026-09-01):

#pragma once

#include <stdbool.h>
#include <stddef.h>
#include <stdint.h>

#include "app/result.h"
#include "common/constants.h"
#include "domain/zones/zone.h"

#define IRRIGATION_CONFIGURATION_SCHEMA_VERSION 1U
#define IRRIGATION_CONFIGURATION_ID_SIZE 32U
#define IRRIGATION_CONFIGURATION_NAME_SIZE 32U
#define IRRIGATION_CONFIGURATION_MAX_STEP_DURATION_MS 3600000U

typedef struct {
    char zone_id[IRRIGATION_CONFIGURATION_ID_SIZE];
    char display_name[IRRIGATION_CONFIGURATION_NAME_SIZE];
} IrrigationZoneConfiguration;

typedef struct {
    char zone_id[IRRIGATION_CONFIGURATION_ID_SIZE];
    uint32_t duration_ms;
} IrrigationProgramStepConfiguration;

typedef struct {
    char program_id[IRRIGATION_CONFIGURATION_ID_SIZE];
    char display_name[IRRIGATION_CONFIGURATION_NAME_SIZE];
    IrrigationProgramStepConfiguration steps[IRRIGATION_MAX_PROGRAM_STEPS];
    uint8_t step_count;
} IrrigationProgramConfiguration;

typedef struct {
    char schedule_id[IRRIGATION_CONFIGURATION_ID_SIZE];
    bool enabled;
    uint8_t weekday_mask;
    uint8_t hour;
    uint8_t minute;
    char program_id[IRRIGATION_CONFIGURATION_ID_SIZE];
} IrrigationScheduleConfiguration;

typedef struct {
    uint16_t schema_version;
    IrrigationZoneConfiguration zones[IRRIGATION_MAX_ZONES];
    IrrigationProgramConfiguration programs[IRRIGATION_MAX_PROGRAMS];
    IrrigationScheduleConfiguration schedules[IRRIGATION_MAX_SCHEDULES];
    uint8_t zone_count;
    uint8_t program_count;
    uint8_t schedule_count;
    uint32_t next_program_id;
    uint32_t next_schedule_id;
} IrrigationConfiguration;

IrrigationResult irrigation_configuration_validate(const IrrigationConfiguration *configuration,
                                                    const Zone *board_zones, size_t board_zone_count);

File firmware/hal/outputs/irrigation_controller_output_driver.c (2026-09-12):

#include "hal/outputs/irrigation_controller_output_driver.h"

#include "common/constants.h"

#define MCP23017_ADDRESS 0x20U
#define MCP23017_SDA_GPIO GPIO_NUM_21
#define MCP23017_SCL_GPIO GPIO_NUM_22
#define MCP23017_I2C_CLOCK_HZ 100000U
#define RELAY_OUTPUT_MASK ((uint8_t)((1U << IRRIGATION_LOCAL_OUTPUT_COUNT) - 1U))

static IrrigationResult ensure_safe_off(IrrigationControllerOutputDriver *driver)
{
    driver->output_mask = 0U;
    return mcp23017_write_port_a(&driver->mcp23017, 0U) == ESP_OK
        ? IRRIGATION_RESULT_OK
        : IRRIGATION_RESULT_INTERNAL_ERROR;
}

static IrrigationResult irrigation_controller_initialize_safe_off(OutputDriver *base)
{
    IrrigationControllerOutputDriver *driver = (IrrigationControllerOutputDriver *)base;
    driver->initialized = false;
    driver->output_mask = 0U;

    const Mcp23017Configuration configuration = {
        .port = I2C_NUM_0,
        .sda_gpio = MCP23017_SDA_GPIO,
        .scl_gpio = MCP23017_SCL_GPIO,
        .address = MCP23017_ADDRESS,
        .clock_hz = MCP23017_I2C_CLOCK_HZ,
    };
    if (mcp23017_init(&driver->mcp23017, &configuration) != ESP_OK) {
        logger_log(&driver->logger, LOG_LEVEL_ERROR, "production_output", "MCP23017 initialization failed");
        return IRRIGATION_RESULT_INTERNAL_ERROR;
    }
    if (mcp23017_configure_port_a_outputs(&driver->mcp23017, RELAY_OUTPUT_MASK) != ESP_OK ||
        ensure_safe_off(driver) != IRRIGATION_RESULT_OK) {
        (void)ensure_safe_off(driver);
        logger_log(&driver->logger, LOG_LEVEL_ERROR, "production_output", "MCP23017 safe output initialization failed");
        return IRRIGATION_RESULT_INTERNAL_ERROR;
    }

    driver->initialized = true;
    logger_log(&driver->logger, LOG_LEVEL_INFO, "production_output", "all relay outputs set OFF");
    return IRRIGATION_RESULT_OK;
}

static IrrigationResult irrigation_controller_set_output(OutputDriver *base, size_t output_index, bool enabled)
{
    IrrigationControllerOutputDriver *driver = (IrrigationControllerOutputDriver *)base;
    if (!driver->initialized) {
        return IRRIGATION_RESULT_INVALID_STATE;
    }
    if (output_index >= IRRIGATION_LOCAL_OUTPUT_COUNT) {
        return IRRIGATION_RESULT_NOT_FOUND;
    }

    const uint8_t output_bit = (uint8_t)(1U << output_index);
    const uint8_t requested_mask = enabled ? (uint8_t)(driver->output_mask | output_bit)
                                           : (uint8_t)(driver->output_mask & (uint8_t)~output_bit);
    if (mcp23017_write_port_a(&driver->mcp23017, requested_mask) != ESP_OK) {
        (void)ensure_safe_off(driver);
        logger_log(&driver->logger, LOG_LEVEL_ERROR, "production_output", "MCP23017 output write failed; requested safe OFF");
        return IRRIGATION_RESULT_INTERNAL_ERROR;
    }

    driver->output_mask = requested_mask;
    logger_log(&driver->logger, LOG_LEVEL_INFO, "production_output", enabled ? "relay output ON" : "relay output OFF");
    return IRRIGATION_RESULT_OK;
}

static IrrigationResult irrigation_controller_get_output(const OutputDriver *base, size_t output_index, bool *enabled)
{
    const IrrigationControllerOutputDriver *driver = (const IrrigationControllerOutputDriver *)base;
    if (!driver->initialized) {
        return IRRIGATION_RESULT_INVALID_STATE;
    }
    if (output_index >= IRRIGATION_LOCAL_OUTPUT_COUNT || enabled == NULL) {
        return IRRIGATION_RESULT_NOT_FOUND;
    }
    *enabled = (driver->output_mask & (uint8_t)(1U << output_index)) != 0U;
    return IRRIGATION_RESULT_OK;
}

static const OutputDriverVTable IRRIGATION_CONTROLLER_OUTPUT_DRIVER_VTABLE = {
    .initialize_safe_off = irrigation_controller_initialize_safe_off,
    .set_output = irrigation_controller_set_output,
    .get_output = irrigation_controller_get_output,
};

void irrigation_controller_output_driver_init(IrrigationControllerOutputDriver *driver, Logger logger)
{
    if (driver != NULL) {
        *driver = (IrrigationControllerOutputDriver){
            .base.vtable = &IRRIGATION_CONTROLLER_OUTPUT_DRIVER_VTABLE,
            .logger = logger,
        };
    }
}

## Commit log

2026-08-30 Complete DEV_KIT control, program and scheduler flow
2026-09-01 Centralize DEV_KIT configuration management
    [configuration_manager.h]
2026-09-01 Add NVS configuration persistence foundation
    [configuration_repository.h, partitions.csv]
2026-09-01 Fix configuration persistence stack usage
    [configuration_manager.h, configuration_repository.h]
2026-09-02 Synchronize scheduler configuration updates
    [configuration_manager.h]
2026-09-12 feat(hal): add production MCP23017 relay output driver
2026-09-16 Add Shelly master valve control for production
2026-09-21 Add production status LED indication
